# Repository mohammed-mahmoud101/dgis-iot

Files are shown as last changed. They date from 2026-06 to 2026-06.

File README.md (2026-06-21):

# Quadruped Robot — IoT Subsystem

IoT control stack for a 12-servo quadruped robot built around an **ESP32**, **PCA9685** servo driver, and **MQTT**-based communication between a laptop control station, a phone gyro bridge, and a Bluetooth gamepad.

> This repository covers the **embedded firmware**, **desktop control station**, **standalone Arduino test sketches**, and **mechanical CAD files** for the robot chassis.

<p align="center">
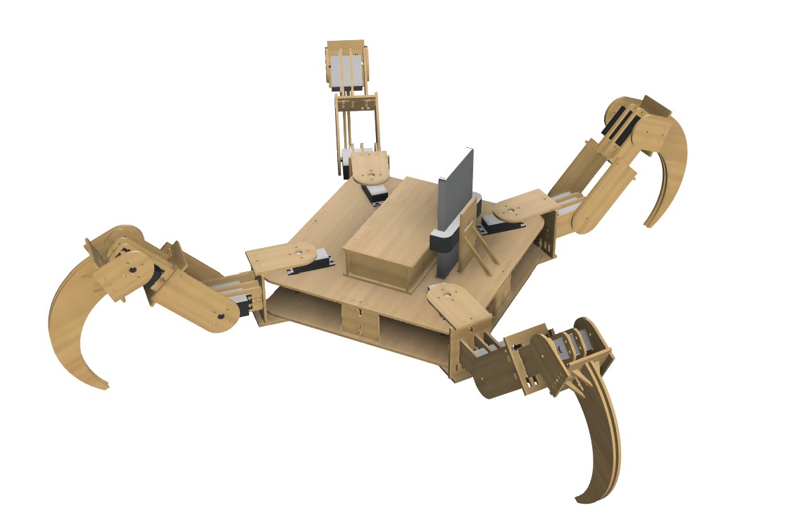
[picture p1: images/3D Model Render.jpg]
3D CAD Render
  
  &nbsp;&nbsp;
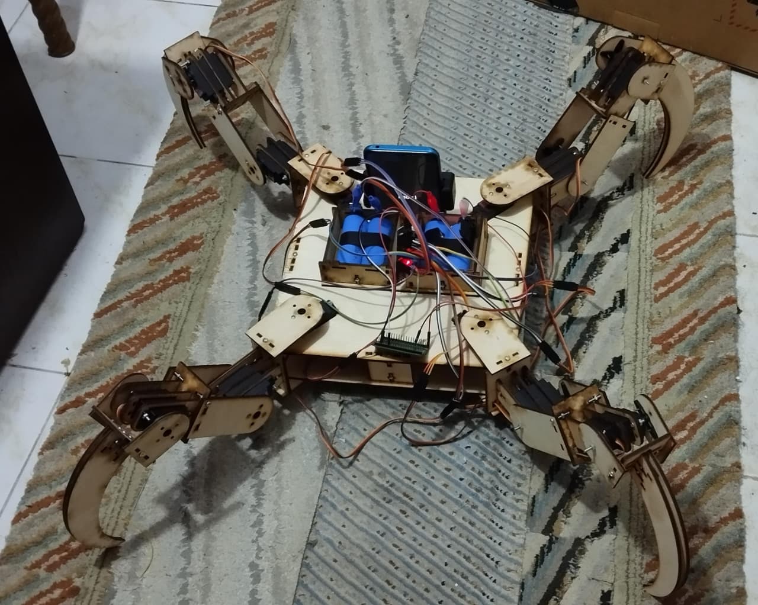
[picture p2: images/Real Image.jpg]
Assembled Robot
  
</p>
<p align="center">
  <em>Left: FreeCAD 3D render &nbsp;|&nbsp; Right: Assembled quadruped with ESP32, PCA9685, and 12 servos</em>
</p>

---

## System Architecture

```
┌─────────────────┐         Bluetooth (Bluepad32)
│  Xbox / Gamepad  │ ──────────────────────────────────┐
└─────────────────┘                                    │
                                                       ▼
┌─────────────────┐   clicks UI    ┌──────────────┐   ┌──────────────────────────┐
│   Laptop User   │ ─────────────► │  Tkinter App │   │  ESP32 + PCA9685         │
└─────────────────┘                │  (Python)    │   │  + 12× SG90/MG90S Servos │
                                   └──────┬───────┘   └────────────▲─────────────┘
                                          │                        │
                                          ▼                        │ USB Serial
                                   ┌──────────────┐               │ (JSON lines)
                                   │  MQTT Broker │               │
                                   │  (embedded   │               │
                                   │   or Mosquitto)│              │
                                   └──────┬───────┘               │
                                          │  WiFi                  │
                                          ▼                        │
                                   ┌──────────────┐               │
                                   │  Phone App   │ ──────────────┘
                                   │  (USB↔MQTT   │
                                   │   bridge)    │
                                   └──────────────┘
```

**Priority arbitration** lives on the ESP32: laptop MQTT commands override the gamepad for ~2 seconds after the last UI command.

---

## Directory Layout

```
dgis-iot/
├── esp32-firmware/           # PlatformIO project — main ESP32 firmware
│   ├── src/main.cpp          #   Bluepad32 gamepad → MQTT + USB serial bridge
│   ├── platformio.ini        #   Board: esp32doit-devkit-v1, Bluepad32 framework
│   ├── include/
│   ├── lib/
│   └── test/
│
├── control-station/          # Python desktop app (Tkinter)
│   ├── s7s_control_station.py#   Calibration, gait control, telemetry, logging
│   └── requirements.txt     #   paho-mqtt, amqtt, matplotlib
│
├── arduino-sketches/         # Standalone Arduino IDE sketches (dev/test)
│   ├── single-leg-ik-demo/   #   Inverse kinematics + Bézier curve single-leg demo
│   │   └── single-leg-ik-demo.ino
│   └── trot-gait-forward/    #   Full 4-leg trot gait (diagonal-pair walking)
│       └── trot-gait-forward.ino
│
├── cad/                      # FreeCAD mechanical design files
│   ├── *.FCStd               #   Assembly & part models (v1.2, v1.3)
│   ├── *.FCBak               #   FreeCAD auto-backups
│   ├── dxfs/                 #   DXF exports for laser cutting
│   ├── nesting/              #   Nesting layout ZIPs for sheet material
│   └── parts_weights.txt    #   Measured component weights
│
└── README.md                 # ← You are here
```

---

## Hardware

| Component | Description |
|---|---|
| **ESP32 DevKit V1** | Main MCU — runs WiFi, MQTT client, Bluepad32 BT stack |
| **PCA9685** | 16-channel I²C PWM driver (address `0x40`) |
| **12× Servos** | 4 legs × 3 joints (abductor / flex / knee) |
| **Gamepad** | Any Bluepad32-compatible controller (Xbox, PS4, etc.) |
| **Phone** | Runs a Kotlin app that bridges USB serial ↔ MQTT |
| **Laptop** | Runs the Python control station (Tkinter GUI) |

### Leg Geometry (from IK sketch)

| Segment | Length |
|---|---|
| Coxa (hip) | 85 mm |
| Femur (upper leg) | 104 mm |
| Tibia (lower leg) | 154 mm |

---

## Getting Started

### 1. ESP32 Firmware (`esp32-firmware/`)

**Prerequisites:** [PlatformIO CLI](https://platformio.org/install/cli) or the PlatformIO VS Code extension.

```bash
cd esp32-firmware

# Edit src/main.cpp — set your WiFi credentials and MQTT broker IP:
#   const char* ssid        = "YOUR_WIFI_SSID";
#   const char* password    = "YOUR_WIFI_PASSWORD";
#   const char* mqtt_server = "YOUR_MQTT_BROKER_IP";

# Build and upload
pio run -t upload

# Monitor serial output
pio device monitor -b 115200
```

The firmware:
- Connects to WiFi and an MQTT broker
- Accepts Bluetooth gamepads via Bluepad32
- Maps D-pad and buttons to MQTT messages (`quadpod/gamepad`)
- Forwards USB serial data from the phone bridge to MQTT

### 2. Control Station (`control-station/`)

**Prerequisites:** Python 3.8+

```bash
cd control-station
pip install -r requirements.txt

# Run with embedded MQTT broker (zero config)
python s7s_control_station.py

# Or use an external Mosquitto broker
python s7s_control_station.py --external-mqtt 192.168.1.10:1883
```

The GUI has four tabs:

| Tab | Purpose |
|---|---|
| **Calibration** | Motor offset sliders (±1.5 rad) + gyro zero-point capture |
| **Controls** | Gait buttons (trot, turn, arc), speed slider, E-STOP |
| **Telemetry** | Live 12-joint angle readout + matplotlib bar plot |
| **Log** | Scrolling log viewer with color-coded levels |

### 3. Arduino Sketches (`arduino-sketches/`)

Open in Arduino IDE (requires `Wire.h` and `Adafruit_PWMServoDriver` library):

- **`single-leg-ik-demo/`** — Tests a single leg using inverse kinematics and cubic Bézier trajectory. Useful for verifying servo wiring, PCA9685 communication, and tuning leg geometry constants.

- **`trot-gait-forward/`** — Full 4-leg trot gait using diagonal pairs (FL+BR, FR+BL). Hardcoded angles with smooth interpolation. Useful for validating mechanical assembly before the full firmware.

### 4. CAD Files (`cad/`)

Open in [FreeCAD](https://www.freecad.org/) (v0.21+). Key assemblies:

| File | Description |
|---|---|
| `quadruped_robot_1.3.FCStd` | Full robot assembly (latest) |
| `assembly_1.3.1.FCStd` | Body frame assembly |
| `leg_assembly.FCStd` | Single leg assembly |
| `first_arm_assembly.FCStd` | Shoulder/coxa arm |
| `side_arm_assembly.FCStd` | Side arm linkage |
| `assembly__battery.FCStd` | Battery compartment |
| `mechanism.FCStd` | Joint mechanism study |

The `dxfs/` folder contains 23 DXF part outlines ready for laser cutting. The `nesting/` folder has sheet nesting ZIPs.

---

## MQTT Topic Reference

### Commands (Laptop → ESP32)

| Topic | Payload | Description |
|---|---|---|
| `quadpod/cmd/gait` | gait name or `"stand"` | Set active gait |
| `quadpod/cmd/speed` | float `0.1–3.0` | Gait speed multiplier |
| `quadpod/cmd/estop` | `"1"` | Emergency stop |
| `quadpod/cmd/calib/motor/start` | _(empty)_ | Enter motor calibration mode |
| `quadpod/cmd/calib/motor/set` | `{"joint":int,"offset":float}` | Set joint offset |
| `quadpod/cmd/calib/motor/save` | _(empty)_ | Save offsets to NVS |
| `quadpod/cmd/calib/motor/load` | _(empty)_ | Load offsets from NVS |
| `quadpod/cmd/calib/motor/end` | _(empty)_ | Exit calibration mode |
| `quadpod/cmd/calib/gyro/set` | `{"yaw":f,"pitch":f,"roll":f}` | Set gyro zero offset |
| `quadpod/cmd/calib/gyro/clear` | _(empty)_ | Clear gyro offset |
| `quadpod/cmd/calib/gyro/save` | _(empty)_ | Save gyro offset to NVS |
| `quadpod/cmd/ping` | _(empty)_ | Connectivity check |

### Gamepad (ESP32 → Broker)

| Topic | Payload | Description |
|---|---|---|
| `quadpod/gamepad` | `"move:forward"`, `"action:A"`, etc. | Button press events |
| `quadpod/system` | status string | Connect/disconnect events |
| `quadpod/logs` | string | USB serial forwarded data |

### State (ESP32 → Laptop)

| Topic | Payload | Description |
|---|---|---|
| `quadpod/state/telemetry` | JSON: gait, pose[12], offsets[12], … | Full telemetry snapshot |
| `quadpod/state/gyro` | JSON: yaw, pitch, roll, valid | Raw gyro from phone |
| `quadpod/state/status` | JSON: esp32Connected, uptime, … | System status |
| `quadpod/log` | JSON: level, msg, t | Structured log messages |

---

## Available Gaits

| ID | Description |
|---|---|
| `stand` | Stand / idle pose |
| `trot_forward` | Trot forward |
| `trot_backward` | Trot backward |
| `turn_left` | Turn left (in place) |
| `turn_right` | Turn right (in place) |
| `arc_left` | Arc left (forward + turn) |
| `arc_right` | Arc right (forward + turn) |

---

## Joint Map

12 servos organized as 4 legs × 3 joints:

| Index | Label | Joint Type |
|---|---|---|
| 0 | `FR_abd` | Front-Right Abductor |
| 1 | `FL_abd` | Front-Left Abductor |
| 2 | `RL_abd` | Rear-Left Abductor |
| 3 | `RR_abd` | Rear-Right Abductor |
| 4 | `FR_flex` | Front-Right Flexor |
| 5 | `FL_flex` | Front-Left Flexor |
| 6 | `RL_flex` | Rear-Left Flexor |
| 7 | `RR_flex` | Rear-Right Flexor |
| 8 | `FR_knee` | Front-Right Knee |
| 9 | `FL_knee` | Front-Left Knee |
| 10 | `RL_knee` | Rear-Left Knee |
| 11 | `RR_knee` | Rear-Right Knee |

---

## Part of DGIS

This repo is a component of the larger DGIS system. See the [main repo](https://github.com/AhmedMohamady1/DGIS) for full architecture.

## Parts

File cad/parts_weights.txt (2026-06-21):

base = 207 g

first_arm = 8 g
first_arm_b = 5 g
first_arm_bridge = 6 g

side_Arm = 11 g
side_arm_free = 9 g
side_arm_bridge = 6 g

leg = 14 g
leg_free = 13 g
leg_bridge = 6 g

servo = 56 g
servo_holder = 2 g
servo_pillar = 5 g

batteries = 350 g
battery_base = 28 g
battery_wall = 5 g
battery_wall_side = 5 g

mohamadi_holder = 9 g
mohamadi_pillars = 2 g

screw = 1 g

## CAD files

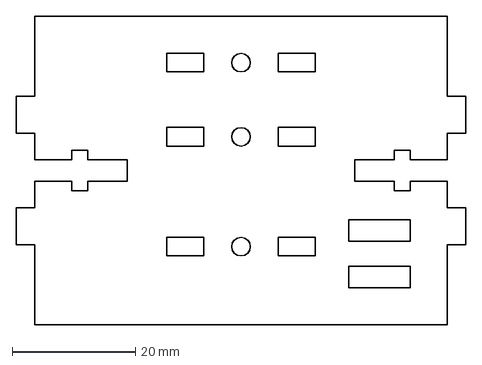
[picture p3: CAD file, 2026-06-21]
cad/dxfs/quadruped_robot_1.3-first_arm_bridge_dx.dxf
72.9 x 50.0 mm

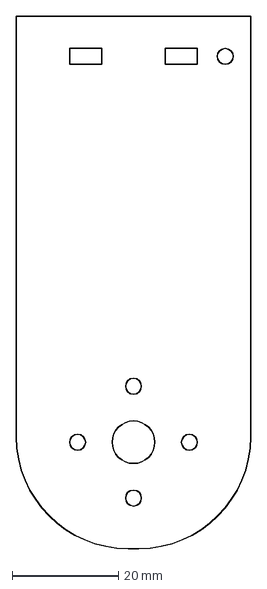
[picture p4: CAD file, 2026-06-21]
cad/dxfs/quadruped_robot_1.3-side_arm_dx.dxf
44.0 x 100.0 mm

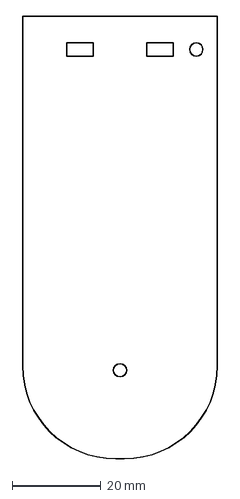
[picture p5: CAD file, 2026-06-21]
cad/dxfs/quadruped_robot_1.3-side_arm_free_dx.dxf
44.0 x 100.0 mm

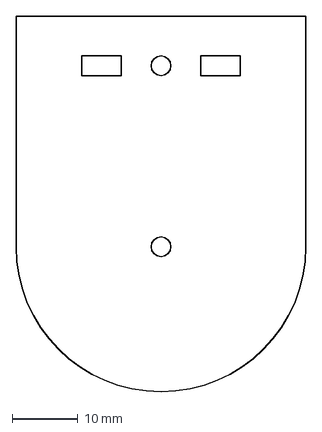
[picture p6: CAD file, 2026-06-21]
cad/dxfs/quadruped_robot_1.3-leg_one_free_dx.dxf
44.0 x 57.0 mm

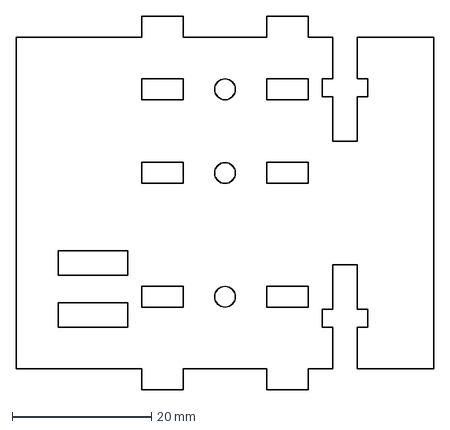
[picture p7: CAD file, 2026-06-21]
cad/dxfs/quadruped_robot_1.3-side_arm_bridge_dx.dxf
60.0 x 53.7 mm

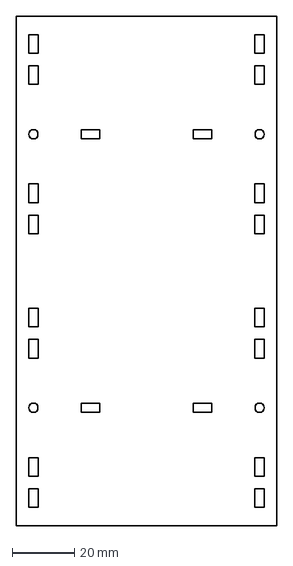
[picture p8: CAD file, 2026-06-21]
cad/dxfs/quadruped_robot_1.3-battery_base_dx.dxf
83.8 x 164.0 mm

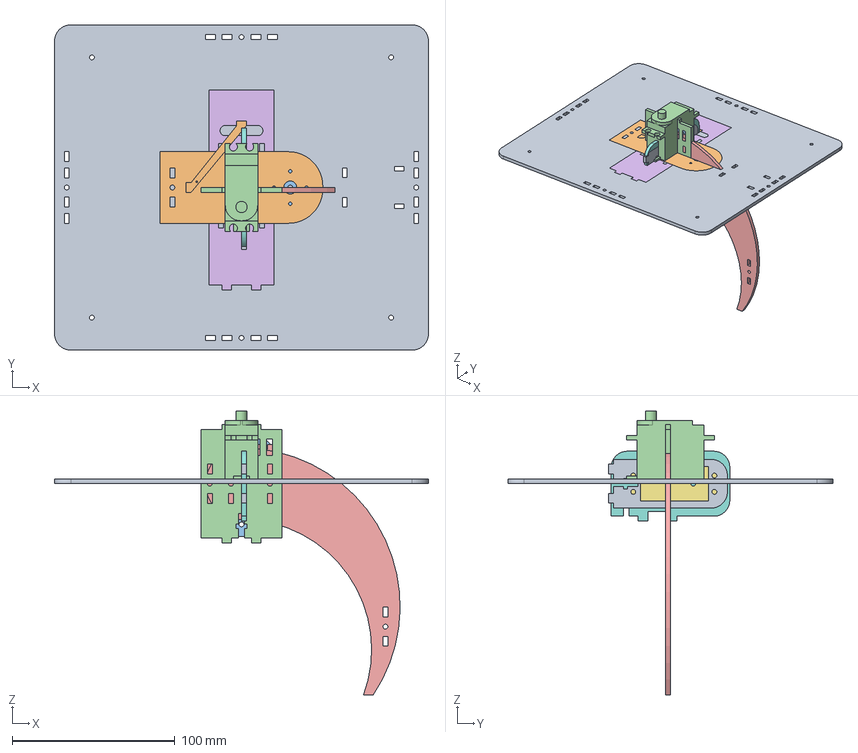
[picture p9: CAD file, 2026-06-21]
cad/quadruped_robot_1.2.FCStd
230.0 x 200.0 x 174.6 mm
base_bot
diagonal_pillar
first_arm_bottom
first_arm_bridge
leg_free
phone_holder_pillar
servo_pillar
servo_pillar_90
servo_holder
side_arm
side_arm_free
servo
base_bridge
leg_bridge
screw

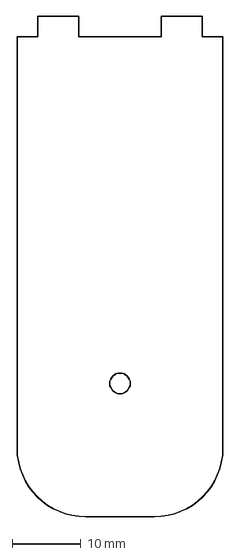
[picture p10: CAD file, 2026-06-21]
cad/dxfs/quadruped_robot_1.3-servo_pillar_dx.dxf
30.0 x 73.0 mm

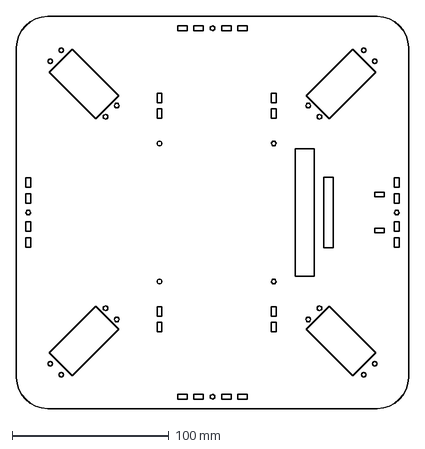
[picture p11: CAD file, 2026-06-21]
cad/dxfs/quadruped_robot_1.3-base_top_dx.dxf
250.0 x 250.0 mm

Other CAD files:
cad/leg_assembly.FCStd
cad/assembly_1.3.FCStd
cad/assembly.FCStd
cad/side_arm_assembly.FCStd
cad/assembly__battery.FCStd
cad/assembly_1.3.1.FCStd
cad/first_arm_assembly.FCStd
cad/quadruped_robot_1.3.FCStd
cad/mechanism.FCStd
cad/dxfs/quadruped_robot_1.3-base_bot_dx.dxf
cad/dxfs/quadruped_robot_1.3-base_bridge_dx.dxf
cad/dxfs/quadruped_robot_1.3-battery_cover_dx.dxf
cad/dxfs/quadruped_robot_1.3-battery_mid_wall_dx.dxf
cad/dxfs/quadruped_robot_1.3-battery_wall_dx.dxf
cad/dxfs/quadruped_robot_1.3-battery_wall_side_dx.dxf
cad/dxfs/quadruped_robot_1.3-diag_pillar_dx.dxf
cad/dxfs/quadruped_robot_1.3-first_arm_bot_dx.dxf
cad/dxfs/quadruped_robot_1.3-first_arm_dx.dxf
cad/dxfs/quadruped_robot_1.3-leg_diag_pillar_dx.dxf
cad/dxfs/quadruped_robot_1.3-leg_one_bridge_dx.dxf
cad/dxfs/quadruped_robot_1.3-leg_one_dx.dxf
cad/dxfs/quadruped_robot_1.3-leg_two.dxf
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

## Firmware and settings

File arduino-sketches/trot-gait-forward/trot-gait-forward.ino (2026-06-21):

#include <Wire.h>
#include <Adafruit_PWMServoDriver.h>

Adafruit_PWMServoDriver pwm;

#define SERVO_MIN 100
#define SERVO_MAX 600
#define PWM_FREQ  50

// ---------------------------------------------------------
// Servo channel map (matches your wiring comment):
//   0  1  2   -> Front-Left  (FL): base, hip, leg
//   3  4  5   -> Front-Right (FR): base, hip, leg
//   6  7  8   -> Back-Left   (BL): base, hip, leg
//   9 10 11   -> Back-Right  (BR): base, hip, leg
// ---------------------------------------------------------
#define FL_BASE 0
#define FL_HIP  1
#define FL_LEG  2

#define FR_BASE 3
#define FR_HIP  4
#define FR_LEG  5

#define BL_BASE 6
#define BL_HIP  7
#define BL_LEG  8

#define BR_BASE 9
#define BR_HIP  10
#define BR_LEG  11

// ---------------------------------------------------------
// Tunable angles - adjust these to match your physical build
// ---------------------------------------------------------
const float NEUTRAL_HIP   = 60;   // standing hip angle (leg down, body supported)
const float NEUTRAL_LEG   = 60;   // standing knee/leg angle
const float LIFT_HIP      = 90;   // hip angle when leg is raised (lifts foot off ground)
const float LIFT_LEG      = 90;   // leg angle when raised

const float BASE_CENTER   = 90;   // base servo "neutral" rotation
const float BASE_FORWARD  = 120;  // base servo swung forward (toward direction of travel)
const float BASE_BACKWARD = 60;   // base servo swung backward (push/drive stroke)

const int   STEP_DELAY    = 15;   // ms between interpolation steps (lower = faster, less smooth)
const int   PHASE_PAUSE   = 200;  // ms pause after each phase completes

// Convert degree (0-180) to PWM pulse
uint16_t degreeToPulse(float degree) {
  degree = constrain(degree, 0, 180);
  return map(degree, 0, 180, SERVO_MIN, SERVO_MAX);
}

void setServo(uint8_t channel, float degree) {
  pwm.setPWM(channel, 0, degreeToPulse(degree));
}

// Smoothly move two legs' worth of servos (6 channels) from current
// angles to target angles together, so motion looks fluid rather than snapping.
void moveServosSmooth(uint8_t channels[], float startAngles[], float endAngles[], int count) {
  int steps = 30;
  for (int s = 0; s <= steps; s++) {
    for (int i = 0; i < count; i++) {
      float angle = startAngles[i] + (endAngles[i] - startAngles[i]) * s / (float)steps;
      setServo(channels[i], angle);
    }
    delay(STEP_DELAY);
  }
}

// ---------------------------------------------------------
// Helper to set one leg's 3 servos directly (no interpolation)
// ---------------------------------------------------------
void setLeg(uint8_t baseCh, uint8_t hipCh, uint8_t legCh,
            float baseDeg, float hipDeg, float legDeg) {
  setServo(baseCh, baseDeg);
  setServo(hipCh,  hipDeg);
  setServo(legCh,  legDeg);
}

// ---------------------------------------------------------
// Stand all 4 legs in neutral position
// ---------------------------------------------------------
void standNeutral() {
  setLeg(FL_BASE, FL_HIP, FL_LEG, BASE_CENTER, NEUTRAL_HIP, NEUTRAL_LEG);
  setLeg(FR_BASE, FR_HIP, FR_LEG, BASE_CENTER, NEUTRAL_HIP, NEUTRAL_LEG);
  setLeg(BL_BASE, BL_HIP, BL_LEG, BASE_CENTER, NEUTRAL_HIP, NEUTRAL_LEG);
  setLeg(BR_BASE, BR_HIP, BR_LEG, BASE_CENTER, NEUTRAL_HIP, NEUTRAL_LEG);
  delay(500);
}

// ---------------------------------------------------------
// Trot gait: diagonal pairs move together.
//   Diagonal A = Front-Left  + Back-Right
//   Diagonal B = Front-Right + Back-Left
//
// One full step cycle for a diagonal pair:
//   1) Lift the pair (raise hip/leg)
//   2) Swing the pair's base servo forward while lifted
//   3) Lower the pair back down (foot plants on ground, forward of start)
//   4) Drive: rotate base servo backward while down -> pushes body forward
// While one diagonal pair does this, the other diagonal pair stays planted
// and its base servos rotate backward in sync with step 4 to also help
// drive the body forward (stance/support phase).
// ---------------------------------------------------------

void liftPair(uint8_t baseA, uint8_t hipA, uint8_t legA,
              uint8_t baseB, uint8_t hipB, uint8_t legB) {
  uint8_t channels[6]   = {hipA, legA, hipB, legB, baseA, baseB};
  float startAngles[6]  = {NEUTRAL_HIP, NEUTRAL_LEG, NEUTRAL_HIP, NEUTRAL_LEG, BASE_BACKWARD, BASE_BACKWARD};
  float endAngles[6]    = {LIFT_HIP, LIFT_LEG, LIFT_HIP, LIFT_LEG, BASE_BACKWARD, BASE_BACKWARD};
  moveServosSmooth(channels, startAngles, endAngles, 6);
}

void swingPairForward(uint8_t baseA, uint8_t baseB) {
  uint8_t channels[2]  = {baseA, baseB};
  float startAngles[2] = {BASE_BACKWARD, BASE_BACKWARD};
  float endAngles[2]   = {BASE_FORWARD, BASE_FORWARD};
  moveServosSmooth(channels, startAngles, endAngles, 2);
}

void lowerPair(uint8_t baseA, uint8_t hipA, uint8_t legA,
               uint8_t baseB, uint8_t hipB, uint8_t legB) {
  uint8_t channels[6]   = {hipA, legA, hipB, legB, baseA, baseB};
  float startAngles[6]  = {LIFT_HIP, LIFT_LEG, LIFT_HIP, LIFT_LEG, BASE_FORWARD, BASE_FORWARD};
  float endAngles[6]    = {NEUTRAL_HIP, NEUTRAL_LEG, NEUTRAL_HIP, NEUTRAL_LEG, BASE_FORWARD, BASE_FORWARD};
  moveServosSmooth(channels, startAngles, endAngles, 6);
}

// Drive stroke: planted feet rotate base servo from FORWARD back to BACKWARD,
// which pushes the body forward over the ground (this is what actually
// propels the robot). Applies to whichever pair is currently down/stance.
void driveStroke(uint8_t baseA, uint8_t baseB) {
  uint8_t channels[2]  = {baseA, baseB};
  float startAngles[2] = {BASE_FORWARD, BASE_FORWARD};
  float endAngles[2]   = {BASE_BACKWARD, BASE_BACKWARD};
  moveServosSmooth(channels, startAngles, endAngles, 2);
}

// One full trot step: swap which diagonal pair is swinging vs driving
void trotStep(bool diagA_swings) {
  if (diagA_swings) {
    // Diagonal A (FL+BR) swings through the air, Diagonal B (FR+BL) drives
    liftPair(FL_BASE, FL_HIP, FL_LEG, BR_BASE, BR_HIP, BR_LEG);
    delay(PHASE_PAUSE);
    swingPairForward(FL_BASE, BR_BASE);
    // simultaneously drive the planted diagonal B backward to push body forward
    driveStroke(FR_BASE, BL_BASE);
    delay(PHASE_PAUSE);
    lowerPair(FL_BASE, FL_HIP, FL_LEG, BR_BASE, BR_HIP, BR_LEG);
    delay(PHASE_PAUSE);
  } else {
    // Diagonal B (FR+BL) swings through the air, Diagonal A (FL+BR) drives
    liftPair(FR_BASE, FR_HIP, FR_LEG, BL_BASE, BL_HIP, BL_LEG);
    delay(PHASE_PAUSE);
    swingPairForward(FR_BASE, BL_BASE);
    driveStroke(FL_BASE, BR_BASE);
    delay(PHASE_PAUSE);
    lowerPair(FR_BASE, FR_HIP, FR_LEG, BL_BASE, BL_HIP, BL_LEG);
    delay(PHASE_PAUSE);
  }
}

void walkForward(int numSteps) {
  bool diagA_swings = true;
  for (int i = 0; i < numSteps; i++) {
    trotStep(diagA_swings);
    diagA_swings = !diagA_swings; // alternate diagonal pairs each step
  }
}

void setup() {
  Serial.begin(115200);
  Serial.println("Quadruped hardcoded forward walk - starting");

  pwm.begin();
  pwm.setPWMFreq(PWM_FREQ);
  delay(500);

  standNeutral();
  delay(1000);

  walkForward(10);   // walk forward 10 trot steps
}

void loop() {
  // Keep walking continuously. Remove/comment this if you only want
  // the 10 steps from setup() and then stop.
  walkForward(1);
}

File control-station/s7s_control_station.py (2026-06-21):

#!/usr/bin/env python3
"""
s7s_control_station.py — Laptop control station for the S7S Quadrupod.

Architecture
------------
    [Xbox controller] ── Bluetooth (Bluepad32) ─►  [ESP32 + PCA9685 + 12 servos]
                                                          ▲
                                                          │  (USB serial, JSON lines)
                                                          │
    [Laptop user]  ────── clicks UI ──────►  [Tkinter app]
                                                 │
                                                 ▼
                                          [Embedded MQTT broker]
                                                 │  (WiFi)
                                                 ▼
                                          [Phone (USB↔MQTT bridge)]
                                                 │  (USB serial, JSON lines)
                                                 ▼
                                          [ESP32 + PCA9685 + 12 servos]

    The Xbox controller connects directly to the ESP32 via Bluetooth (Bluepad32).
    Priority is handled on the ESP32: laptop MQTT commands override Xbox for 2
    seconds. The laptop app does NOT touch the Xbox — it only displays the
    priority state reported by the ESP32 in telemetry/status.

Priority
--------
    Priority arbitration lives entirely on the ESP32 firmware. The laptop merely
    sends commands over MQTT; the ESP32 decides whether each command should
    override the Xbox (it does, for MANUAL_OVERRIDE_S seconds after any laptop
    command). The ESP32 reports the current priority state back to the laptop
    via the status topic (mqttOverrideActive, controllerConnected).

MQTT topics
-----------
    Commands (laptop → phone → ESP32):
        quadpod/cmd/gait                    payload: gait name (str) or "stand"
        quadpod/cmd/speed                   payload: float (0.1 – 3.0)
        quadpod/cmd/estop                   payload: "1"
        quadpod/cmd/calib/motor/start       payload: (empty)
        quadpod/cmd/calib/motor/set         payload: {"joint":int,"offset":float}
        quadpod/cmd/calib/motor/save        payload: (empty)
        quadpod/cmd/calib/motor/load        payload: (empty)
        quadpod/cmd/calib/motor/end         payload: (empty)
        quadpod/cmd/calib/gyro/set          payload: {"yaw":f,"pitch":f,"roll":f}
        quadpod/cmd/calib/gyro/clear        payload: (empty)
        quadpod/cmd/calib/gyro/save         payload: (empty)
        quadpod/cmd/ping                    payload: (empty)

    State (ESP32 → phone → laptop):
        quadpod/state/telemetry             payload: {"gait","gaitTime","pose[12]","offsets[12]","gyro_calibrated","calibMode","calibJoint"}
        quadpod/state/gyro                  payload: {"yaw","pitch","roll","valid"}   (raw, from phone)
        quadpod/state/status                payload: {"esp32Connected","calibMode","uptime"}
        quadpod/log                         payload: {"level","msg","t"}

Usage
-----
    python s7s_control_station.py
    python s7s_control_station.py --broker-port 1883
    python s7s_control_station.py --external-mqtt 192.168.1.10:1883
"""

from __future__ import annotations

import argparse
import json
import logging
import socket
import sys
import threading
import time
import queue
from dataclasses import dataclass, field
from typing import Any, Callable, Optional

import tkinter as tk
from tkinter import ttk, messagebox

# ─── Optional deps ────────────────────────────────────────────────────────────
try:
    import paho.mqtt.client as mqtt  # type: ignore
    PAHO_OK = True
except ImportError:
    PAHO_OK = False

try:
    from amqtt.broker import Broker  # type: ignore
    AMQTT_OK = True
except ImportError:
    AMQTT_OK = False

# pygame/Xbox support removed — the Xbox controller now connects directly to
# the ESP32 via Bluetooth (Bluepad32). The laptop no longer polls it.
PYGAME_OK = False

try:
    import matplotlib
    matplotlib.use("TkAgg")
    import matplotlib.pyplot as plt
    from matplotlib.backends.backend_tkagg import FigureCanvasTkAgg
    MPL_OK = True
except ImportError:
    MPL_OK = False


# =============================================================================
#  Configuration
# =============================================================================

DEFAULT_BROKER_PORT = 1883
DEFAULT_BROKER_HOST = "192.168.1.12"   # the laptop itself
MQTT_CLIENT_ID = "s7s_control_station"
TELEMETRY_RATE_HZ = 20              # how often we *request* telemetry from ESP32
# Reference only — the actual override window is enforced on the ESP32
# firmware (laptop MQTT commands override Xbox for this many seconds).
MANUAL_OVERRIDE_S = 2.0
JOINT_LIMIT = 1.5                   # rad — clamp range for calibration sliders (~±86°)

JOINT_LABELS = [
    "FR_abd", "FL_abd", "RL_abd", "RR_abd",
    "FR_flex", "FL_flex", "RL_flex", "RR_flex",
    "FR_knee", "FL_knee", "RL_knee", "RR_knee",
]
JOINT_GROUPS = [
    ("Abductor",  ["FR_abd", "FL_abd", "RL_abd", "RR_abd"]),
    ("Flex",      ["FR_flex", "FL_flex", "RL_flex", "RR_flex"]),
    ("Knee",      ["FR_knee", "FL_knee", "RL_knee", "RR_knee"]),
]

GAITS = [
    ("stand",         "Stand / Idle"),
    ("trot_forward",  "Trot Forward"),
    ("trot_backward", "Trot Backward"),
    ("turn_left",     "Turn Left"),
    ("turn_right",    "Turn Right"),
    ("arc_left",      "Arc Left"),
    ("arc_right",     "Arc Right"),
]

# =============================================================================
#  MQTT topic registry — single source of truth, shared by all components
# =============================================================================

class Topics:
    # Commands (laptop → ESP32, via phone bridge)
    CMD_GAIT            = "quadpod/cmd/gait"
    CMD_SPEED           = "quadpod/cmd/speed"
    CMD_ESTOP           = "quadpod/cmd/estop"
    CMD_CALIB_MOTOR_START = "quadpod/cmd/calib/motor/start"
    CMD_CALIB_MOTOR_SET   = "quadpod/cmd/calib/motor/set"
    CMD_CALIB_MOTOR_SAVE  = "quadpod/cmd/calib/motor/save"
    CMD_CALIB_MOTOR_LOAD  = "quadpod/cmd/calib/motor/load"
    CMD_CALIB_MOTOR_RESET = "quadpod/cmd/calib/motor/reset"
    CMD_CALIB_MOTOR_END   = "quadpod/cmd/calib/motor/end"
    CMD_CALIB_GYRO_SET    = "quadpod/cmd/calib/gyro/set"
    CMD_CALIB_GYRO_CLEAR  = "quadpod/cmd/calib/gyro/clear"
    CMD_CALIB_GYRO_SAVE   = "quadpod/cmd/calib/gyro/save"
    CMD_PING             = "quadpod/cmd/ping"

    # State (ESP32 → laptop, via phone bridge)
    STATE_TELEMETRY     = "quadpod/state/telemetry"
    STATE_GYRO          = "quadpod/state/gyro"
    STATE_STATUS        = "quadpod/state/status"
    LOG                 = "quadpod/log"

    # Wildcard the phone bridge subscribes to (kept here for parity / docs)
    CMD_WILDCARD        = "quadpod/cmd/#"

    ALL_SUBSCRIBED = [
        STATE_TELEMETRY, STATE_GYRO, STATE_STATUS, LOG,
    ]
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
